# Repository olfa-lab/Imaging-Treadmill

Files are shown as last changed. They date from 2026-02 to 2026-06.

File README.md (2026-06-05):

## Treadmill for Imaging/Stimulation of Head Fixed Mice
  This is a treadmill for use in imaging and stimulation rigs. The design allows the animal to move and relieve stress over the course of a session while maintaining complete stability for clear signal. The treadmill is simple to assemble and was created to address concerns with weight, cost, and space. Most notably, this design accommodates the load-tolerance parameters of a goniometer, thus allowing the whole assembly to be precisely angled to achieve the most suitable field of view.

All components referenced in the assembly instructions below are listed their respective folders (.STL files for 3D printed components and specs/links for hardware).
## ASSEMBLY INSTRUCTIONS ##
### Rotation stage:
- Drill out the threads of the two middle through-holes in the metal base so that they are smooth 1/4-20 clearance holes.
- Use set screws to firmly attach metal posts on both sides of the base.
- Slide the 3D printed treadmill frame onto the base + post assembly.
- Use middle two holes in the base of the assembly to secure the base to the rotation stage/platform with 1/4-20 screws.
### Head fix clamp:
- Slide the two clamps into the channels at the top of the 3D printed frame.
- Secure directly to each mounting post with a screw and washer.
- Adjust distance by loosening the screw, sliding the clamp into position, and re-tightening the screw.
### Treadmill:
- 3D print treadmill component.
- Use tip of soldering iron to set heat-set inserts into holes in the rail guides.
- Securely attach Teflon tape along the middle track and the inside of the adjacent tracks of the treadmill.
- Place LEGO 24-tooth gears in each slot of the treadmill (4 total).
- Fasten the gears in place by threading a LEGO axle through the holes in the treadmill and the gears.
- Assemble LEGO treads, lay two strips (one over each row of gears) and snap them together.
- Lower treadmill onto the assembly (shorter end forward) and secure at desired height using a screw and washer through the slider hole/heat set insert.   
### DiamondPost (Headbar)
- diamond_post_standard_MK2 is mainly used for imaging setup. It has been designed for Nikon 16/0.8 and 10X/0.5 while using water as an immersion medium. 
- The depth of well can be smaller if you want to use less viscous medium (such as ultrasound gel).

### Versions
Mihaly Voroslakos did some modifications and his version can be found
https://github.com/misiVoroslakos/3D_printed_designs/tree/main/Treadmill_Rinberg

### Parts
Part list can be reached here. 
https://github.com/misiVoroslakos/3D_printed_designs/blob/main/Treadmill_Rinberg/BOM_Treadmill_Rinberg.txt 

### Sample image (prototype 1.5" post version, all other dimensions identical to 2" post version in this repo)






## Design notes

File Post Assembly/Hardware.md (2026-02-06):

The above STL file is not meant to be 3D printed. It is a reference for the post assembly onto which the treadmill and treadmill frame are mounted.

The assembly consists of the following hardware:
- (2X) RS2 - Ø1" Pillar Post, 1/4"-20 Taps, L = 2" : https://www.thorlabs.com/thorproduct.cfm?partnumber=RS2
- (1X) Siskiyou - BB Series Building Block, BB-5.0, 5", Imperial Threads, SKU: 09360000E, https://siskiyou.com/bb-series-building-block/

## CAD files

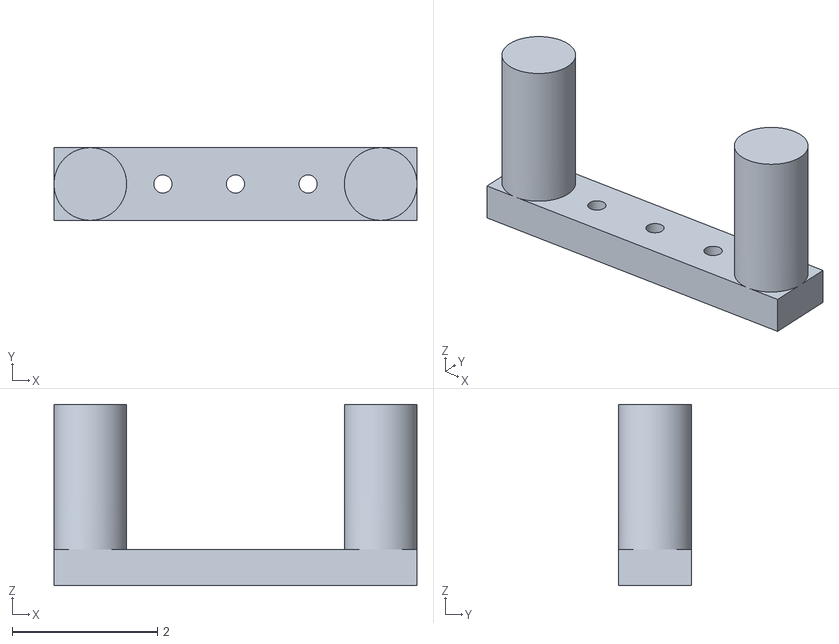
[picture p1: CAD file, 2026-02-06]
Post Assembly/ModelofMountingPosts_2in_20260206.stl
5.00 x 1.00 x 2.50

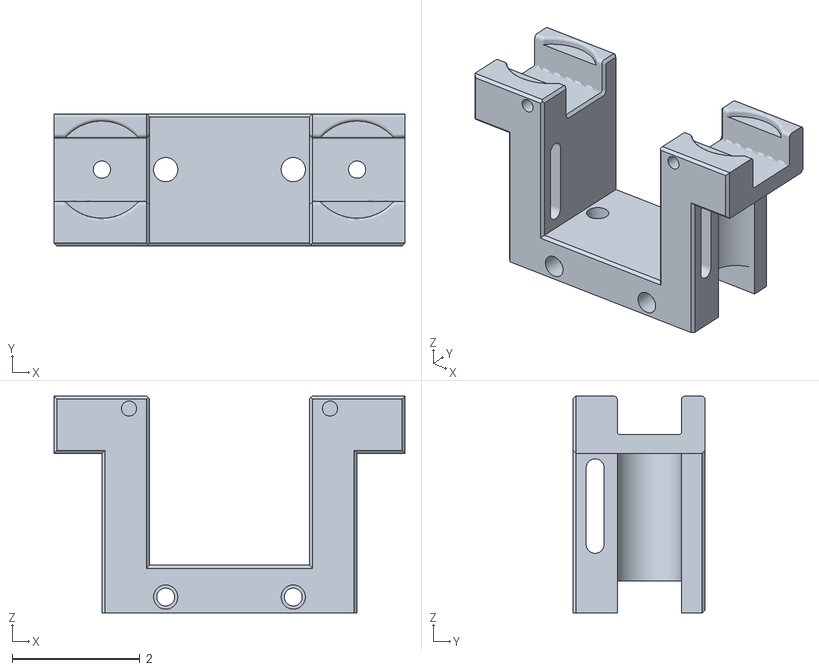
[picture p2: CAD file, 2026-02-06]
Treadmill Frame/TreadmillFrame_2inPosts_Updated20260206.stl
5.50 x 2.07 x 3.40

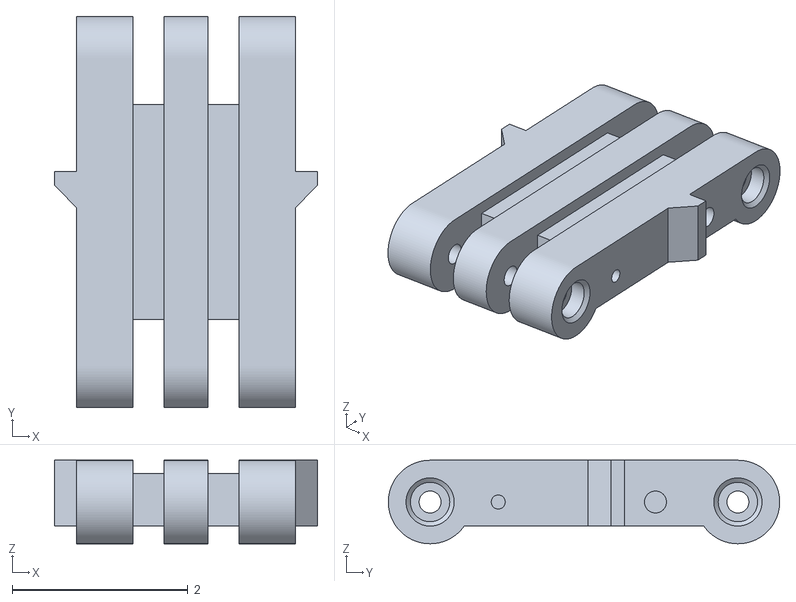
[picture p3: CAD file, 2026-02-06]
Treadmill/Treadmill_Updated20260206.stl
2.99 x 4.45 x 0.95
